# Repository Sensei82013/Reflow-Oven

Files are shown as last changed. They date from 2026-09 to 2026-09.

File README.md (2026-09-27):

# Reflow Oven Controller

A toaster oven converted into a PCB reflow oven, driven by a custom
STM32F103 board with a K-type thermocouple, a solid state relay and a 7"
Nextion touch panel.

The firmware runs a PI loop on the MCU. A host can steer it either from a
small web app over SWD (working today) or from the Nextion panel
(in progress).

---

## System

```mermaid
flowchart LR
    MAINS["120 V AC mains"] --> PSU["PSU<br/>120 VAC to 24 VDC"]
    PSU -->|24 V| SSR["SSR-25DD<br/>solid state relay<br/>3-32 V in, 25 A"]
    SSR -->|switched 24 V| HEAT["Heating element<br/>3.6 ohm, 160 W"]
    HEAT -.->|heat| TC["K-type thermocouple"]
    TC --> MAX["MAX6675<br/>cold-junction comp<br/>+ 12-bit ADC"]
    MAX -->|SPI| MCU["STM32F103C8T6<br/>custom PCB"]
    MCU -->|PA8 PWM<br/>TIM1_CH1| SSR
    MCU <-->|USART1<br/>PA9/PA10| NEX["Nextion NX8048P070-011C<br/>7in 800x480 capacitive"]
    MCU <-->|SWD| HOST["Host PC<br/>OpenOCD + web app"]
    PSU5["5 V supply, 1 A"] --> NEX
```

### Bill of the major pieces

| Part | Detail | Notes |
|---|---|---|
| **MCU** | STM32F103C8T6 | Custom PCB, OSHPark. 64 MHz from **HSI** - the 8 MHz crystal Y1 is not populated |
| **Temperature** | K-type thermocouple to MAX6675 | SPI, 0.25 °C resolution, 220 ms conversion. Terminal block J5 |
| **Heater switch** | SSR-25DD | DC-DC, 3-32 V control, 5-200 V DC out, 25 A. Driven from PA8 |
| **Heating element** | 3.6 Ω at 24 V | 6.7 A, **160 W**. Hugely oversized for bench setpoints - see `skill.md` |
| **Power** | 120 VAC to 24 VDC | Feeds the element through the SSR |
| **Display** | Nextion NX8048P070-011C | 7", 800x480, capacitive, *Intelligent* series. **Needs its own 5 V at 1 A** - no USB power |
| **Debug** | ST-Link V2 on J2 | 3V3 / SWDIO / SWCLK / GND only. **No NRST** |

### Pin map

| Signal | MCU pin | Net / test point |
|---|---|---|
| MAX6675 `~CS` | PA4 | `Thermo_CS`, TP2, indicator D4 |
| MAX6675 `SCK` | PA5 | `Thermo_SCK`, TP3 |
| MAX6675 `SO` | PA6 | `Thermo_SO`, TP4 |
| SSR control | PA8 | `Relay`, J6, TIM1_CH1, indicator D3 |
| USART1 TX -> Nextion RX | PA9 | TP6 |
| USART1 RX <- Nextion TX | PA10 | TP5 (5 V tolerant) |
| SWD | PA13 / PA14 | J2 |

Two board quirks worth knowing before wiring anything:

- **J4 (the 5 V serial header) does not work.** Its BSS138 level shifters are
  rotated one pin position, so a signal arriving there reaches only a MOSFET
  gate - there is no DC path to the MCU. Go directly to **PA9 / PA10**
  (TP6 / TP5). No level shifting is needed in either direction.
- **SW1 selects BOOT0.** In the +3.3 V position the part boots from SRAM and
  never runs your firmware. It belongs in the **GND** position.

---

## Repository layout

```
Hardware/
  KiCad/            schematic, PCB, gerbers, BOM, 3D step
Software/
  webapp/           browser UI + Python bridge (bridge.py, index.html)
  run_webapp.ps1    build, flash, serve the web app
  run_profile.ps1   open-loop step tests, PI profiles, hardware probes
  run_monitor.ps1   plain thermocouple monitor
  Display/          Nextion HMI designs
  Embedded/
    Thermo_Monitor/ the live firmware (all current work)
    Reflow_Oven_STM32_SOURCE_V1_1/  original 2021 firmware, Nextion HMI
    Reflow_Oven_STM32_Source/       earlier revision
skill.md            project goal, architecture and the pitfalls found so far
```

---

## Quick start

Everything is driven from `Software/`, with the ST-Link connected. The
STM32CubeIDE toolchain is used in place, so nothing extra needs installing;
`make` comes from Git Bash.

```powershell
# live temperature only
.\run_monitor.ps1 -Seconds 30

# browser UI: setpoint + Kp/Ki in, temperature and duty out
.\run_webapp.ps1 -Kp 0.2 -Ki 0.002 -MaxDuty 1.5
# then open http://127.0.0.1:8770/

# open-loop step test, for characterising the plant
.\run_profile.ps1 -Mode step -PwmHz 1 -StepDuty 10 -BaseSeconds 180 -Seconds 500 -Csv step.csv
```

The firmware builds in several modes, selected at compile time:

| `MODE=` | What it does |
|---|---|
| *(none)* | thermocouple monitor, no heating |
| `pi` | fixed 30/40/50 °C profile with dwells |
| `step` | open-loop step at a fixed duty, for plant characterisation |
| `hold` | park the output at a duty so the driver can be probed |
| `server` | PI loop steered from the host over SWD - used by the web app |
| `nextion` | **PI loop driven from the Nextion panel** - Start/Stop arm it, Apply sets setpoint and gains, telemetry goes back to the screen |
| `hmi` | Nextion first-contact probe - baud sweep, pin checks, frame dump |
| `tx` / `rx` | continuous transmit / raw receive capture, for tracing wiring |

---

## Status

**Working:** thermocouple readings, SSR drive, PWM on TIM1_CH1, PI loop on
the MCU, web app with live charts and a dead-man switch, all the safety
cutoffs.

**Working on the panel:** wire it **straight to PA9 / PA10** - not J4, whose
level shifters are miswired. `MODE=nextion` is a full controller driven from
the screen: Start and Stop arm and disarm the loop, Apply sets the setpoint
and gains, and the firmware pushes temperature, setpoint, duty, error, state,
the status LED, the P/I split and the trend waveform back to the panel. The
object map is `Software/Display/README.txt`.

**Remaining on the panel:** a run on real hardware to confirm the arming path
end to end. Note the trend waveform's `add` command takes a single byte, so
the trace clips above about 91 °C - fine for bench work, not for a reflow
profile.

**Not started:** reflow profiles proper (soak / ramp / peak / cool),
enclosure, mains-side safety.

See `skill.md` for the detail, and especially for the things that cost real
time to discover.

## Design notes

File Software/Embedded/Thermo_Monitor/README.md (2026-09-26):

# MAX6675 thermocouple live monitor

A small standalone firmware for the Reflow Oven board (STM32F103C8T6) that does
nothing but read the MAX6675 and report the temperature. It never drives the
relay.

## Pin map (from `Reflow Project Kicad.xml`)

| Signal | MCU pin | Net / test point |
|---|---|---|
| MAX6675 `~CS` | PA4 | `Thermo_CS`, TP2 |
| MAX6675 `SCK` | PA5 | `Thermo_SCK`, TP3 |
| MAX6675 `SO`  | PA6 | `Thermo_SO`, TP4 |
| USART1 TX | PA9 | TP6 |
| USART1 RX | PA10 | TP5 |
| Relay | PA8 | J6 (held low here), indicator D3 |

Two indicator LEDs are useful while debugging: **D4 (red) sits on `Thermo_CS`
through R5**, so it is lit whenever CS is high — i.e. whenever this firmware is
actually running and holding the MAX6675 deselected. D4 dark on USB power means
the chip is not executing the flash image at all. **D3 (red) is on the relay
line.** Note D3/D4/R5/R10 postdate `Reflow Project Kicad.xml`; they exist only
in the current `.kicad_sch`.

## Output

The same line goes out three ways, so it can be watched with or without extra
hardware:

1. **USART1, 115200 8N1** on PA9/TP6.
2. **ARM semihosting** over SWD, so an attached ST-Link shows it with no
   USB-serial adapter. Guarded on `C_DEBUGEN`, so the board still runs
   standalone with no debugger.
3. **A telemetry struct at `0x20000000`** that a debugger can poll while the
   core keeps running: `magic("TMP1"), seq, raw, milli_c, fault, uptime_ms,
   sysclk_hz, on_hse`. `seq` is written last, so a changed `seq` means the
   rest is consistent.

Format is `seq,raw,tempC,status`, twice a second.

## Build and run

From Git Bash:

```bash
make
./run_monitor.sh 30                # flash, start, stream 30s of output
./run_monitor.sh 30 --run-only     # skip flashing
```

From Windows PowerShell, which cannot execute `.sh` files, use the equivalent
`.ps1` (note the leading `.\` — PowerShell does not run commands from the
current directory without it):

```powershell
.\run_monitor.ps1 -Seconds 30
.\run_monitor.ps1 -RunOnly
```

Building still needs `make`, so either use Git Bash or build in STM32CubeIDE.
Both runners use the STM32CubeIDE 1.15.0 bundled toolchain, CubeProgrammer and
OpenOCD; no separate installs are needed.

**Only the ST-Link needs to be plugged in.** It supplies 3.3 V to the board
through J2 pin 1 (CubeProgrammer and OpenOCD both report the target voltage,
~3.22 V here) and carries the semihosting output. USB is optional, and powering
from both at once is fine. USB alone gives you a running board but no console —
watch D4, or hang a USB-serial adapter on PA9/TP6 at 115200 8N1.

## Heater control

`control.c` drives the element through the IRF520N on PA8 (the "Relay" net,
J6), which is TIM1_CH1, so duty cycle is real hardware PWM at 200 Hz. D3 sits
on the same net and dims with duty.

```powershell
.\run_profile.ps1 -Mode pi                  # 30/40/50 C profile, PI control
.\run_profile.ps1 -Mode pi -Kp 8 -Ki 0.4    # retune without editing source
.\run_profile.ps1 -Mode step -StepDuty 100  # open-loop step, for tuning
.\run_profile.ps1 -Mode hold -StepDuty 100  # park the output to probe it
.\run_profile.ps1 -Mode pi -Csv out.csv     # also save the rows
```

One script because PowerShell 5.1 has no `&&`; it shells the `make` out to Git
Bash, flashes, runs, and captures. Gains are `-D` macros, so retuning is a
command-line argument rather than a source edit.

### Tuning it for this element

A 41 C setpoint with Kp 12 / Ki 0.6 peaked at **151 C**. Fitting that run
gives the plant, and the numbers explain everything:

| | |
|---|---|
| time constant | ~162 s |
| steady-state gain | **~3860 C per 100% duty** |
| energy delivered | 4.75 full-power-seconds |
| resulting rise | 113 C, i.e. ~24 C per full-power-second |

Duty actually needed to *hold* a setpoint (ambient ~28 C):

| setpoint | duty |
|---|---|
| 41 C | **0.34%** |
| 60 C | 0.83% |
| 100 C | 1.9% |
| 250 C | 5.8% |

The element keeps dumping heat for ~27 s after duty reaches zero, so overshoot
is set by the duty you are *at* when you arrive - not by how fast you cut:

| arriving at | overshoot |
|---|---|
| 0.5% | ~3 C |
| 1.5% | ~10 C |
| 5% | ~32 C |
| 10% | ~64 C |

That is the whole story. Kp 12 commands 100% duty at 8 C of error on a plant
that needs a third of one percent, and by the time the probe reacts the energy
is already committed.

**Suggested starting point:**

```powershell
.
un_webapp.ps1 -Kp 0.2 -Ki 0.002 -MaxDuty 1.5
```

Use `-MaxDuty 0.5` if you want overshoot in the low single digits and are
happy with a slower approach. Raise the ceiling as the setpoint rises - 250 C
needs about 6%. `-MaxDuty` and `-OverTemp` are compiled in; the page cannot
raise them.

Gains are carried as micro-units (x1e6) rather than milli, because Ki of 0.002
is only two counts at a thousandth - not enough resolution to tune with. The
page's step sizes match: 0.01 for Kp, 0.001 for Ki.

**The real fix is less power.** This element is roughly a hundred times
oversized for bench setpoints; the entire useful control range is 0-2% duty,
which is also an awkward pulse width for an SSR at 1 Hz. Running the element
from a lower supply - 12 V quarters the power, 6 V cuts it sixteen-fold -
moves the working range into a comfortable 5-25% band and makes the loop far
better behaved. A real oven with a chamber full of thermal mass will behave
differently again, so treat all of this as calibration of the bench rig.

### Safety

In the firmware: any sensor fault forces duty to 0 (a controller that cannot
see temperature must not drive a heater); above 120 C the output latches off
until reset; every stage times out rather than sitting at full power forever;
the profile switches off and reports DONE.

In the host script: PA8 is forced low through the debugger *before and after*
every run, by enabling the GPIOA clock, clearing the output bit and switching
the pin to a push-pull output while the core is halted. That way neither a
crash nor a halted core can leave the element energised. Reset (SW2) also
drops the gate.

### Status: no heat reaches the thermocouple

The driver stage is fine. Two things were measured that rule it out: PA8's own
pin readback matches the commanded duty exactly, and there is **24 V across
the element at 100% duty**. A MOSFET failing to enhance would drop that supply
across itself and leave the element near 0 V, so the IRF520N is conducting -
an earlier note here blamed its gate threshold and was wrong.

The clean measurement is a cold start: three minutes with the heater off, then
six minutes at 100% duty.

| Segment | Mean |
|---|---|
| heater off, settled (120-180 s) | 27.71 C |
| 100% duty, after 5-6 min (480-540 s) | 27.42 C |
| **steady-state rise** | **-0.29 C** |

Zero, within the MAX6675's 0.25 C quantisation. Six minutes at full power
moves the sensor by nothing at all.

**Two earlier readings of this were wrong, both for the same reason.** The
first step test used a 30-second window and showed nothing, which was read as
"no heating". A later fit gave +15.3 m C/s and was read as "heating, but
slowly". That slope was residual heat from the *previous* run still working
through the rig - this bench holds heat between tests, and the 6-minute run
was climbing 0.4 C/s during its own heater-*off* baseline. Only a cold start
with a long settled baseline measures the heater rather than the last test.
Use `-BaseSeconds 180`.

So: the element dissipates power, and essentially none of it arrives at the
thermocouple. In likely order:

- **Thermal coupling.** If the element is warm to the touch while the probe
  reads ambient, the probe is not seeing it. Still air is an excellent
  insulator; a millimetre of it is enough to hide a low-power element. The tip
  needs physical contact - clamped, taped with foil or kapton, thermal paste.
- **Delivered power.** Measure the element's resistance; 24 V across R gives
  R/576 watts. That the IRF520N passes the current with only 3.3 V on its gate
  suggests the current, and therefore the power, is small.
- **Losses.** An element in open air with no enclosure sheds most of what it
  makes. The real oven will behave completely differently.

No gain value fixes a plant whose output never reaches the sensor. The stage
timeout exists so the firmware reports that rather than sitting at 100%
forever.

### Driving it with an SSR instead

An opto-isolated DC SSR (e.g. SSR-25DD, 3-32 V in, 5-200 V DC out, 25 A) is a
fine replacement for the IRF520N module here - 6.7 A against a 25 A rating is
comfortable, and a resistive element needs no flyback path. Three things to
get right:

1. **Drop the PWM frequency.** An SSR's opto output takes on the order of a
   millisecond to switch. At the 200 Hz default that is a large fraction of
   every 5 ms period spent in transition: it never switches cleanly and the
   SSR heats. Use time-proportioned control instead - `-PwmHz 1`. A plant with
   a minutes-long time constant does not notice, and duty resolution stays at
   0.05% because the period is always 2000 counts.
2. **3.3 V input is the bottom of the range.** PA8 supplies 3.3 V; "3-32 V"
   includes it with no margin at all. If it switches unreliably, buffer it -
   VBUS (5 V) is on J4 pin 3 - or keep the MOSFET module as the buffer stage.
   Input current is typically 7-15 mA, within PA8's budget. D3 + R10 stay in
   parallel on the Relay net and are harmless.
3. **Heatsink it, and watch polarity.** At 6.7 A even a 0.3 V drop is ~2 W.
   DC SSRs are polarity-sensitive on *both* input and output.

Note this part is DC-only. A mains-powered oven needs the AC version.

The cheaper fix is a logic-level MOSFET (IRLZ44N, IRLB8721) in place of the
IRF520N, which keeps 200 Hz switching. The SSR buys isolation and headroom.

### Commissioning a working switch

3.6 ohm at 24 V is 160 W - far more than these setpoints need, and enough to
overshoot hard before a 250 ms loop can react. Start capped and gentle:

```powershell
.\run_profile.ps1 -Mode step -PwmHz 1 -StepDuty 10 -BaseSeconds 180 -HeatSeconds 240 -Seconds 500 -Csv step10.csv
.\run_profile.ps1 -Mode pi -PwmHz 1 -MaxDuty 20 -DwellSeconds 60 -Csv pi.csv
```

The step test at low duty gives a rise curve to pick gains from without
cooking anything. Raise `-MaxDuty` only once the response is known.

## Web app

`run_webapp.ps1` builds the server firmware, flashes it, starts OpenOCD and
serves a small control page:

```powershell
.\run_webapp.ps1                      # 1 Hz PWM, initial duty cap 20%
.\run_webapp.ps1 -MaxDuty 60 -Setpoint 45
.\run_webapp.ps1 -NoBuild             # skip the build entirely
.\run_webapp.ps1 -ForceFlash          # reflash even if unchanged
```

Then open <http://127.0.0.1:8770/>. Ctrl-C stops everything.

**It only flashes when the chip does not already hold this image.** The binary
is read back and compared first, so restarting the app does not erase/program
on every launch or reset the board out from under whatever was running.
`-ForceFlash` overrides, and the build is incremental so an unchanged tree is
a no-op too.

**The duty cap is a runtime value.** `-MaxDuty` seeds it; the page changes it
live, and the page's fields adopt whatever the bridge started with so they
never misreport the live cap. `MAX_DUTY` in the Makefile is a different thing:
a build-time hard ceiling for a firmware that physically cannot exceed some
duty. It defaults to 100 so the UI control is honest - lower it only when you
want that guard baked in.

It shows live temperature, setpoint, duty and error, charts temperature
against setpoint and duty on a second axis-free chart below, and lets you set
a setpoint, cap the duty, start and stop.

### How it reaches the board

The board has no network of its own - no Ethernet, and USB device mode is out
while Y1 is unpopulated - so the only live path is SWD:

```
browser <-- HTTP --> webapp/bridge.py <-- TCL --> OpenOCD <-- SWD --> board
```

The firmware (`MODE=server`) runs the PI loop itself at 4 Hz. OpenOCD reads
and writes target memory through the DAP **while the core keeps running**, so
the control loop is never halted by the UI. The bridge finds both blocks by
running `nm` over the ELF, so the layout is never duplicated between firmware
and host.

**The page sends three numbers and nothing else: setpoint, Kp, Ki.** Duty is
computed on the MCU and only reported back, so a stalled browser or a slow
HTTP round trip can never stretch or skip a control step.

Both blocks use the same discipline: the writer fills the fields and bumps
`seq` last; the reader only acts on a block whose seq changed. A half-written
update cannot be acted on.

### The loop

Textbook PI with two details worth knowing:

- **The integral stores accumulated error (C.s), not an output contribution.**
  The I term is always `Ki * integ_err`, so retuning Ki does not leave history
  that means something different than it did a moment ago.
- **Ki changes are bumpless.** When Ki moves, `integ_err` is rescaled so the I
  term comes out where it already was. Without that, nudging Ki while hot
  steps the output - and on this element that is a real temperature
  excursion, not a cosmetic glitch.
- Anti-windup is conditional integration: accumulate only when the result
  would not be against a stop.

P and I are published separately from the duty they sum to, and the page plots
all three. Seeing which term is doing the work is the whole game when tuning
by hand.

### Safety

- **Dead-man switch.** The firmware only heats while it receives a heartbeat,
  and the bridge only relays that heartbeat while a client has called the API
  within 2.5 s. Close the tab and the output stops within a few seconds.
  Verified: enable -> `running`, client silent 9 s -> `host timeout` at 0%.
- **Explicit re-arm.** After a dead-man trip the firmware clears its own
  enable flag, so heating never resumes just because a browser reconnected -
  it takes a new Start. `push_command` refreshes the heartbeat *before* the
  seq write, otherwise that Start would be latched and cleared in the same
  cycle and nothing would ever re-arm it.
- Sensor fault forces duty to 0; over 120 C latches off until reset; duty is
  capped by `-MaxDuty` on top of whatever the loop asks for.
- Setpoint and duty are range-checked in the bridge as well as clamped in
  firmware. The browser is the least trustworthy part of the chain.

The bridge binds to 127.0.0.1 only. Don't expose it - there is no auth, and
the far end is a 160 W heater.

## Board quirks this firmware works around

These are properties of the board, not of the code, and they cost real time to
rediscover:

- **No NRST on the debug header.** J2 carries only 3V3/SWDIO/SWCLK/GND. `NRST`
  reaches only pushbutton SW2. A debugger therefore cannot pull reset, and
  `mode=UR` / plain `reset` do not do what they normally would.
- **SW1 sets the boot mode, and the +3.3V position bricks the board.** SW1 is
  an SPDT between +3.3V (pin 1) and GND (pin 3), feeding BOOT0 through R1;
  BOOT1/PB2 is unconnected and floats high, so BOOT0 high selects boot-from-
  SRAM and the chip never executes flash — after a reset the PC lands in SRAM.
  **SW1 belongs in the GND position**, where it is now; the board then boots
  the firmware on its own, on USB power, with no debugger attached.
- **Stale breakpoints.** CubeProgrammer's flash loader leaves a hardware
  breakpoint armed in SRAM, which traps the core as soon as it runs. The run
  script issues `rbp all` / `rwp all` before resetting.
- **Interrupt masks survive a manual start.** Only relevant if you start the
  core by hand rather than resetting it: a previous HardFault leaves `PRIMASK`
  set, SysTick then never ticks, `HAL_GetTick()` freezes, and every HAL
  timeout loop — including the HSE-ready wait — spins forever.
- **J4, the 5 V serial header, does not work - its level shifters are
  miswired.** (An earlier note here said U2's `OE` was tied low; that was read
  off the stale `.xml` netlist. **U2 does not exist on the current board at
  all** - it was replaced by two BSS138s, Q1 and Q2.)

  A BSS138 bidirectional shifter wants gate on the +3.3V *rail*, source on the
  3.3V signal, drain on the 5V signal. As built, the three connections are
  rotated one position (symbol pins are 1=G, 2=S, 3=D):

  | | gate (pad 1) | source (pad 2) | drain (pad 3) |
  |---|---|---|---|
  | Q2 (TX) | `3.3_USART1_TX_v1` (PA9) | `/USART1_TX_5V` (J4.2) | dead end -> R8 -> VBUS |
  | Q1 (RX) | `3.3_USART1_RX_v1` (PA10) | `/USART1_RX_5V` (J4.1) | dead end -> R7 -> VBUS |

  So on TX the part runs as a source follower: a high comes out at roughly
  3.3V - Vgs(th), about 2 V, and a low leaves the pin floating because nothing
  pulls J4.2 down. On RX the gate is the MCU's *input*: when the far end pulls
  the source low the FET conducts, but that only drags the dangling drain
  down - PA10 stays at 3.3 V through R6 and never sees a low. Both directions
  are broken.

  Usable UART is therefore at **TP6 (PA9, TX) and TP5 (PA10, RX)**, both plain
  3.3 V with 10k pull-ups (R9, R6). To make J4 live at 3.3 V instead, bridge
  pads 1-2 of Q1 and Q2 (1.90 mm apart, one 0603 zero-ohm each); R7/R8 then
  just hold the floating drains at 5 V, which is harmless.

## Clocking: no crystal fitted

**Y1 is not populated**, so there is no HSE. The firmware runs from the
internal oscillator instead — HSI/2 through PLL x16 = 64 MHz — and says so at
startup:

```
SYSCLK 64000000 Hz (internal HSI, Y1 not populated), sampling every 500 ms
```

HSI is inside the MCU, so nothing needs routing. The only cost is accuracy:
roughly +/-1% at room temperature and a few percent across the full range,
against tens of ppm for a crystal. That does not matter here — the MAX6675
does its own conversion and SCK has no minimum rate — and it is comfortably
inside what a 115200 UART tolerates.

What it does rule out is **USB device mode**, which needs 48 MHz derived from
an HSE PLL and cannot be synthesised from HSI on an F103. So J1 is power-only
unless Y1 gets populated, even though D+/D- and the R2 pull-up are routed.

If the crystal is ever fitted, build with `-DUSE_HSE=1` (or flip `USE_HSE` in
`Core/Src/main.c`) to get 72 MHz from it; the code still falls back to HSI if
it fails to start, rather than hanging.

## Schematic and PCB audit of U4

Checked against the MAX6675 datasheet pinout (1 GND, 2 T-, 3 T+, 4 VCC,
5 SCK, 6 ~CS, 7 SO, 8 N.C.). **The design is correct** - the fault is not in
the routing:

| Pin | Datasheet | Board | Copper |
|---|---|---|---|
| 1 | GND | GND | GND pour, F.Cu + B.Cu |
| 2 | T- | GND | GND pour, F.Cu + B.Cu |
| 3 | T+ | `Net-(U4-T+)` -> J5.1 | track |
| 4 | VCC | +3.3V | track |
| 5 | SCK | `Thermo_SCK` -> PA5, TP3 | track |
| 6 | ~CS | `Thermo_CS` -> PA4, TP2 | track |
| 7 | SO | `Thermo_SO` -> PA6, TP4 | track |
| 8 | N.C. | unconnected | none (correct) |

- **Continuity verified in copper**, not just in the netlist: for each of
  `Thermo_SCK`, `Thermo_CS` and `Thermo_SO`, the MCU pad, the test point and
  the U4 pad all land on a single connected island. SCK specifically runs
  U1.15 -> TP3 -> U4.5 unbroken.
- **T- is grounded**, as the datasheet's typical application circuit requires.
  It connects through the pour rather than a track, which is why a
  segments-only check wrongly reports it as unrouted - the board has 8 zones,
  including GND pours on both layers.
- **Decoupling is present**: C18 (100n) sits 5.3 mm from U4 across +3.3V/GND,
  satisfying the datasheet's bypass recommendation.
- Not fitted, and optional per the datasheet: a filter capacitor across
  T+/T-. Worth adding only if readings turn out noisy once the part responds.

One note for whoever reflows U4: pins 1 and 2 tie straight into a pour on both
layers with `connect_pads yes` and no thermal relief, so they sink a lot of
heat. That makes a hand-soldering iron much less effective on that side.

### Pin-to-pin short test

`probe_shorts()` rules out the other defect that fits the symptom: a bridge
between the adjacent pins 5/6/7. If CS and SO were bridged, SO would simply
mirror CS - high while deselected, low throughout a transfer - which looks
exactly like all-zeros data. The test pulls SO *down* while CS is high; the
MAX6675 releases SO then, so a 1 would mean CS is driving it through a bridge.
Measured result:

```
short: CS->SO=0  SCK->SO=0/1  SCK->CS=0/0
short: no pin-to-pin short found
```

No bridge. (`SCK->CS` reading 0/0 rather than 0/1 is just D4+R5 loading the CS
net - a 1k5 LED leg beats the MCU's ~40k internal pull-up. Harmless, since the
firmware drives CS push-pull.)

## Resolved: U4 VCC pin was lifted

**Fixed 2026-09-19.** The MAX6675's 3V3 pin (4) was lifted off its pad. The
part still answered chip select the whole time — SO released when CS went
high and was driven low when CS went low — because the die was scavenging
power through its I/O clamp diodes from CS. That is enough to work the output
stage but not the shift register, so every word came back `0x0000`.

Worth remembering, because it is a genuinely misleading failure: **a part that
responds to CS is not necessarily powered.** The symptom is indistinguishable
from a missing clock, and the design audit above was needed to get there —
schematic and PCB were both correct.

After reseating the pin:

```
SYSCLK 64000000 Hz (internal HSI, Y1 not populated), sampling every 500 ms
bus: SO(CS=1)=1 SO(CS=0)=0  SCK readback hi=1 lo=0
bus: SO per clock = 0000001101111001
1,0x0381,28.00,OK
2,0x0371,27.50,OK
3,0x0389,28.25,OK
```

Readings sit within +/-0.25 C, which is one MAX6675 LSB — quantisation, not
noise. `RUN_BUS_PROBE` is now 0; set it back to 1 if the sensor ever goes
quiet again.

### If it goes quiet again

The startup diagnostics distinguish the likely causes without a meter:

| `bus:` line | Meaning |
|---|---|
| `SO(CS=1)=1 SO(CS=0)=0`, all-zero words | Part answers CS but cannot shift — VCC or SCK not reaching the die |
| `SO(CS=1)=1 SO(CS=0)=1` | Nothing driving SO at all — part absent, or CS/SO open |
| `short:` reports a bridge | Solder bridge between the adjacent pins 5/6/7 |
| Words read `0xFFFF` | SO floating; reported as `NO_SENSOR_REPLY` |
| D2 set in the word | Thermocouple unplugged; reported as `OPEN_THERMOCOUPLE` |

`0x0000` and `0xFFFF` are both rejected rather than reported as 0 C.

With a meter, probe the U4 pins themselves rather than the test points — the
test points only prove the trace, not the joint. Pin 4 to pin 1 should read
3.3 V, and pin 6 should read 3.3 V while idle. For the clock:

```bash
make SCK_TEST=1 && ./run_monitor.sh 5
```

holds CS low and drives SCK as a 1 kHz square wave, which a DC meter reads as
roughly half of 3.3 V, so **TP3 and U4 pin 5 should both sit near 1.6 V**.
TP3 at 1.6 V with pin 5 stuck at 0 V or 3.3 V localises the break to the chip.
Rebuild with plain `make` afterwards.

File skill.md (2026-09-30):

# Reflow Oven - project brief and hard-won pitfalls

Read this before touching the hardware. Nearly every item below cost hours to
find and looks like something else when you hit it.

---

## Goal

Turn a toaster oven into a PCB reflow oven. An STM32F103 reads a K-type
thermocouple through a MAX6675, drives a 160 W element through a solid state
relay, and runs a PI loop to hold temperature. A 7" Nextion panel is the
intended user interface; a browser app over SWD exists as a working stand-in.

The end goal is a proper reflow profile - soak, ramp, peak, cool - commanded
from the panel.

---

## Architecture

The PI loop lives **on the MCU** and owns the duty cycle. Hosts only supply a
setpoint and gains. That boundary is deliberate: a stalled browser or a slow
HTTP round trip can then never stretch or skip a control step.

```
browser  --HTTP-->  webapp/bridge.py  --TCL-->  OpenOCD  --SWD-->  board
```

The board has no network of its own and USB device mode is unavailable (see
the crystal note below), so SWD is the only live path. OpenOCD reads and
writes target memory through the DAP **while the core keeps running**, so the
UI never halts the control loop.

Two RAM blocks carry the traffic, `g_cmd` and `g_srv`, located by running
`nm` over the ELF rather than hard-coding addresses. Both use the same
discipline: the writer fills the fields and bumps `seq` **last**, and the
reader acts only on a block whose seq changed, so a half-written update can
never be acted on.

---

## Pitfalls

### Flashing and boot

- **No NRST on the debug header.** J2 carries only 3V3/SWDIO/SWCLK/GND, so a
  debugger cannot pull reset and `mode=UR` does not do what it normally does.
  Reset goes through the Cortex-M `SYSRESETREQ` bit instead - see
  `openocd.cfg`.
- **SW1 selects BOOT0, and the wrong position looks like a dead board.** With
  BOOT1/PB2 floating high, BOOT0 high means boot-from-SRAM and the part never
  executes flash; after reset the PC lands around `0x2000xxxx`. **SW1 belongs
  in the GND position.** Visible tell: D4 (on `Thermo_CS`) is lit whenever
  firmware is actually running.
- **CubeProgrammer leaves a hardware breakpoint armed** in SRAM, which traps
  the core the moment it runs. Issue `rbp all` / `rwp all` before resetting.
- **Interrupt masks survive a manual start.** If you ever start the core by
  hand rather than resetting it, a previous HardFault leaves `PRIMASK` set;
  SysTick then never ticks, `HAL_GetTick()` freezes, and every HAL timeout
  loop spins forever - including the HSE-ready wait, which looks like a
  hung boot.

### Clock

- **Y1 is not populated.** There is no HSE. Everything runs from HSI through
  the PLL at 64 MHz. Do not treat "HSE not ready" as a fault.
- Consequence: **USB device mode can never work** as populated, because the
  F103 needs 48 MHz from an HSE PLL. J1 is power-only despite D+/D- and the
  R2 pull-up being routed.

### Build system

- **Changing a `-D` flag used to silently keep stale objects.** Object files
  depend on sources, not on the command line, so `make MODE=server
  MAX_DUTY=10` after a `MAX_DUTY=30` build did nothing and shipped the old
  binary. Combined with the runner's flash-skip, a requested duty ceiling
  silently never existed and the heater overshot by 30 °C. Fixed with a flags
  stamp (`build/flags.stamp`) that every object depends on. If a `-D`
  controlled limit seems not to take effect, hash the binary before and after
  rather than trusting "Nothing to be done".

### Thermocouple

- **A part that answers chip select is not necessarily powered.** The MAX6675
  once returned `0x0000` forever while still releasing SO when CS went high
  and driving it low when CS went low. It was scavenging power through its
  I/O clamp diodes from CS - its **3V3 pin was lifted**. The symptom is
  indistinguishable from a missing clock. Check power *at the pin* before
  suspecting the clock or the code.
- `0x0000` and `0xFFFF` are **not** valid frames and are reported as
  `NO_SENSOR_REPLY`, never as 0 °C. An unplugged thermocouple sets D2 and
  reads `OPEN_THERMOCOUPLE` instead.
- The design was audited against the datasheet and is correct: pinout matches,
  SCK/CS/SO are continuous in copper, C18 decouples VCC, T- is grounded.
  **Gotcha when auditing this PCB:** it has 8 copper zones, and the syntax is
  `(zone (net 2) (net_name "GND")`. A segments-and-vias-only continuity check
  wrongly reports every pour-connected pad as unrouted - U4 pin 2 especially.

### Heater drive

- **The original IRF520N could not switch this load from 3.3 V logic.**
  R_DS(on) is specified at V_GS = 10 V and V_GS(th) is 2-4 V, so a 3.3 V gate
  leaves it near threshold. Replaced with an SSR-25DD, which works.
- **The module is a low-side switch**, so measuring V+ to GND reads 24 V
  whether or not the FET conducts. That measurement fooled us into clearing
  the driver when it was in fact the problem. Measure **drain to source**, or
  across the element.
- **SSRs cannot follow fast PWM.** An opto-isolated DC SSR takes roughly a
  millisecond to switch, so at 200 Hz it never switches cleanly. Duty
  resolution stays at 0.05 % because the period is always 2000 counts.
  `PWM_HZ` now **defaults to 1**; the old 200 Hz default belonged to the
  IRF520N and, left in place, is a silent no-op. At 200 Hz a 1 % duty is a
  48 us pulse, about twenty times shorter than the relay can respond to, so
  the loop reports a sensible duty and the element gets nothing at all.
- **Halting the core does NOT stop the heater** - TIM1 is hardware and keeps
  driving PA8. A capture that ended early once left the element at 3.25 % duty
  indefinitely with no control loop behind it, because the host script's park
  step never got to run. `heater_init()` now sets `__HAL_DBGMCU_FREEZE_TIM1()`,
  so any debugger halt stops the timer too. Treat "the debugger stopped" as a
  state that must be safe by construction, not one the tooling cleans up.
- **`heater_off()` is destructive, so arming again must be explicit.** It stops
  the timer and reconfigures PA8 as a plain GPIO output low, deliberately, so
  the pin is held down by the GPIO block even if the timer misbehaves. But
  `heater_set()` only writes CCR1, which does nothing in that state - so any
  mode that called `heater_off()` during setup could never produce output
  again, at any duty. `heater_set()` now re-arms when it is asked for a
  non-zero duty and finds `TIM1_CEN` clear. Verify with the registers, not the
  log: the loop happily prints "HEATING duty 1.0 %" with the output dead.
  `GPIOA_CRH` nibble 0 must read `A`, not `2`, and `CR1` bit 0 must be set.
- **Very low duties are near the relay's limit.** Holding 41 C needs 0.34 %,
  which at 1 Hz is a 6.8 ms pulse against a switching time of about 1 ms. It
  works, but the delivered energy is non-linear down there. If that becomes a
  problem the answer is a longer time-proportioning window, not a gain change -
  or a less absurdly oversized element.

### The plant itself

Measured, not guessed:

| | |
|---|---|
| Time constant | ~162 s |
| Steady-state gain | **~3860 °C per 100 % duty** |
| Energy to temperature | ~24 °C per full-power-second |

Duty needed to **hold** a setpoint (ambient ~28 °C): **0.34 % at 41 °C**,
0.83 % at 60 °C, 1.9 % at 100 °C, 5.8 % at 250 °C.

The element keeps dumping heat for ~27 s after duty reaches zero, so
**overshoot is set by the duty you are at when you arrive**, not by how fast
you cut:

| arriving at | overshoot |
|---|---|
| 0.5 % | ~3 °C |
| 1.5 % | ~10 °C |
| 5 % | ~32 °C |
| 10 % | ~64 °C |

So textbook gains are actively dangerous here. Kp = 12 %/°C commands full
power at 8 °C of error on a plant that needs a third of one percent; a run to
a 41 °C setpoint peaked at **151 °C**. Start around **Kp 0.2, Ki 0.002,
`-MaxDuty 1.5`** and raise the ceiling only as the setpoint rises.

Gains are carried as micro-units (x1e6) rather than milli, because Ki of 0.002
is only two counts at a thousandth - not enough resolution to tune with.

**This is dead-time dominated.** No gain value fixes that; the duty ceiling
does the real work. Note also that the element position and insulation are
expected to change, so do not over-tune the current rig.

### Nextion panel

**Wire the panel straight to PA9 / PA10. That works.**

| Panel | Board |
|---|---|
| TX | **PA10** (TP5) - 5 V tolerant, no level shifter needed |
| RX | **PA9** (TP6) - 3.3 V drive is sufficient |
| GND | board GND |
| 5 V | its own supply - 430 mA typical, 1 A recommended |

**Do not use J4.** Its BSS138 shifters have the pins rotated one position, so
a signal arriving there lands on a MOSFET gate and there is simply no DC path
to the MCU. Everything else - baud, levels, grounds - was a red herring; this
was the whole problem, and it cost a lot of time. TP5/TP6 sit directly on the
MCU nets with nothing in between.

Confirmed working once moved: the panel answers `sendme` with
`66 00 FF FF FF` at 9600, and `dim=` visibly changes the backlight.

The panel is an **NX8048P070-011C**: 7", 800x480, capacitive, *Intelligent*
series, default baud 9600, **no USB power**.

See `Software/Display/README.txt` for the full object map - that file is the
contract, and `MODE=nextion` implements it. Four things about it shape the
firmware:

- **Search the HMI for `prints`, not `print`.** An earlier audit of this panel
  concluded that Start and Stop emitted nothing, because the grep only looked
  for `print`. They use `prints "p0b20"` / `prints "p0b21"` and always worked.
  A wrong "the panel sends nothing" sends you looking at wiring for no reason.
- **Page scope matters, but only for some objects now.** `xPV/xSP/xDuty/xErr`
  and `xSPset/xKp/xKi` are `vscope=global` and can be written from any page.
  `tState`, `tLed`, `tMode`, `tAlarm`, `tPI` and the waveform `s0` are still
  page-local, so writing them while another page is up returns `1A`. The
  firmware tracks the page from the nav codes `p0b10/11/12` and gates only
  those. Monitor is page **0** and the boot page - do not assume page 1.
- **9600 baud is only ~960 byte/s, and that is a real constraint.** Four
  `x.val=` writes per 250 ms cycle is already a quarter of the link. Send the
  numbers every cycle and the text and colours only when they change,
  otherwise the queue backs up and the screen lags behind the plant.
- **Never leave `bkcmd=1` on.** It makes the panel return a bare `0x01` after
  every command, and those acks are single bytes with no terminator. Four
  telemetry writes per 250 ms cycle fill a 64-byte frame buffer in about four
  seconds, after which every arriving byte is discarded and no touch code is
  ever parsed again. The failure is silent and deeply misleading: telemetry is
  TX-only so the screen keeps updating perfectly, and the dead-man stays happy
  because bytes *are* arriving - only the parser is jammed. It presents as
  "the buttons do nothing". Use `bkcmd=0`, and make buffer overflow reset the
  frame rather than drop the bytes that would have ended it.
- **Do not poll the UART from the control loop.** The MAX6675 conversion is
  220 ms of a 250 ms cycle and the telemetry writes are blocking on top of it,
  so a polled receive gets almost no time, drops bytes, and the dead-man trips
  at random - it looks exactly like a flaky panel or a bad wire. `MODE=nextion`
  claims `USART1_IRQn` (unused by this project's MSP) and receives into a ring
  buffer instead. A cycle that overruns also resyncs its deadline rather than
  chasing it, so it never spirals.
- **The waveform `add` command takes a single byte.** `add 1,0,<y>` cannot
  address rows above 255, so with the contract's 2.8 px/°C scale the trace
  clips at about 91 °C. Enough for bench work; a reflow profile will need
  either a coarser scale or `addt` bulk transfer.

### Long unattended runs

A 30-minute hold test cannot have a debugger attached for its duration, and
getting that right took several attempts:

- **Semihosting output is the hazard.** Any attach sets `C_DEBUGEN`; a
  `bkpt #0xAB` reached while no servicer is listening halts the core *for
  good*. So merely peeking at a run kills it - a read-only check stopped a
  hold test dead. Build long runs with **`NX_QUIET=1`**, which makes the mode 8
  loop silent, and the board can then be attached to and read at will. Note
  `main()`'s own banner is still noisy, so the arming session must enable
  semihosting even for a quiet build.
- **Read the trace, not the log.** `g_trace` is a RAM ring - 512 samples of
  temperature and duty at 5 s, i.e. 42 minutes - read over SWD afterwards.
  `g_nx` carries the panel counters the same way.
- **Detach by clearing `C_DEBUGEN`**: `mww 0xE000EDF0 0xA05F0000` as the last
  command. OpenOCD's `shutdown` leaves it set, so the firmware would otherwise
  halt at its next bkpt.
- **Read memory without halting.** `mdw` works on a running target. Issuing
  `resume` to an already-running core errors with `not halted` and **aborts
  the rest of the OpenOCD command sequence**, which is how one peek skipped
  its own `C_DEBUGEN` cleanup and killed the run.
- **Background tasks get truncated** somewhere around 5 minutes, and a
  truncated capture is exactly the case that used to leave the heater on.

### Measuring things - lessons

Two of our own instruments gave confidently wrong answers:

- **HAL calls inside a timing loop measure themselves.** A pin rise-time test
  using `HAL_GPIO_ReadPin` returned a constant 40 cycles regardless of the
  pin, because that *was* the loop overhead. Use raw register access
  (`GPIOA->IDR`, `GPIOA->BSRR`) and measure the floor explicitly.
- **`HAL_UART_Transmit_IT` needs the USART1 NVIC line**, which this firmware's
  MSP never enables. It queues a transfer that can never run, leaves `gState`
  stuck at `BUSY_TX`, and silently turns every later `HAL_UART_Transmit` into
  a no-op. Poll `TXE` and write `DR` directly.

---

## Safety

Present in firmware and worth preserving:

- Any sensor fault forces duty to 0. A controller that cannot see temperature
  must not drive a heater.
- Above `OVERTEMP` (default 120 °C) the output **latches off**. Temperature
  keeps being published while latched - that is exactly when you want to see
  it. In `MODE=nextion`, **STOP clears the latch** once the oven has cooled
  below `OVERTEMP_REARM_C` (15 °C of hysteresis). Until that was added the
  latch was cleared nowhere in the firmware at all, so one trip meant
  power-cycling the board before it would heat again - which presents as "the
  controller is stuck". Requiring a real cool-down keeps STOP a reset button
  rather than a bypass.
- Every profile stage times out rather than sitting at full power forever.
- **Dead-man switch:** the firmware only heats while it receives a heartbeat,
  and the bridge only relays that heartbeat while a client has called the API
  within 2.5 s. Close the browser tab and the output stops within seconds.
  After a trip the firmware clears its own enable flag, so heating never
  resumes just because a browser reconnected - and `push_command` refreshes
  the heartbeat *before* the seq write, otherwise an explicit Start would be
  latched and cleared in the same cycle and nothing would ever re-arm.
- The host scripts force PA8 low through the debugger before and after every
  run, so neither a crash nor a halted core can leave the element energised.
- `MAX_DUTY` and `OVERTEMP` are compiled in; the UI cannot raise them.

The bridge binds to 127.0.0.1 only. Do not expose it - there is no auth and
the far end is a 160 W heater on mains-derived power.

---

## Suggested next steps

1. Run `MODE=nextion` on the bench and confirm the arming path end to end:
   Start turns `tState` green and raises duty, Stop drops it, Apply moves the
   setpoint. The semihosting log prints every touch code it decodes, so a
   button that does nothing is easy to tell from a button that was never sent.
2. Fix the trend waveform's 91 °C ceiling - see the `add` note above.
3. Re-characterise the plant once the element position and insulation are
   final, then set gains and the duty ceiling from that.
5. Implement proper reflow profiles on top of the working setpoint loop.

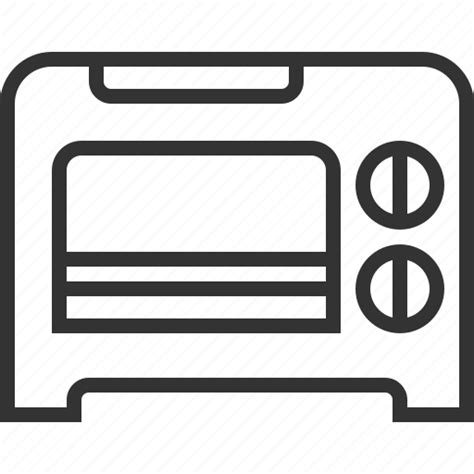
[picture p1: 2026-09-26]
Hardware/KiCad/th.jpg

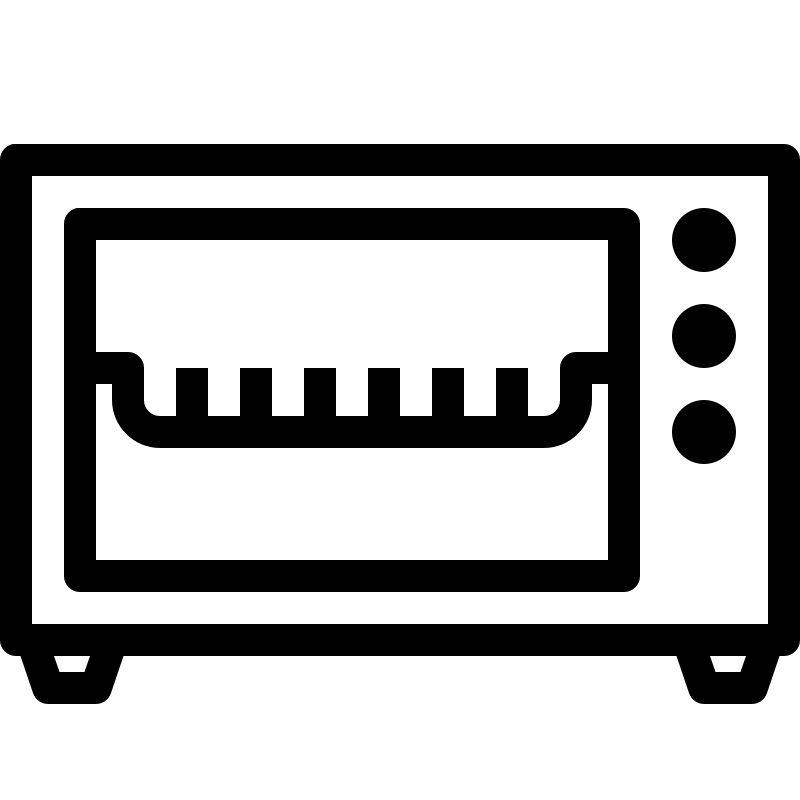
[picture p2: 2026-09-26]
Hardware/KiCad/toaster-oven-svgrepo-com.png

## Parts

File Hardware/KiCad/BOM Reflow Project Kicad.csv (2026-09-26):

Id | Designator | Footprint | Quantity | Designation | Supplier and ref
1 | R4,R2 | R_0603_1608Metric | 2 | 1k5
2 | R3,R1 | R_0603_1608Metric | 2 | 10k
3 | U4 | SOIC127P600X175-8N | 1 | MAX6675ISA_
4 | J3,J5 | CUI_TB001-500-02BE | 2 | CUI_TB001-500-02BE
5 | H1,H2,H3,H4 | MountingHole_3.2mm_M3_DIN965_Pad | 4 | GND
6 | SW1 | SW_EG1271A | 1 | SW_Nidec_CAS-120A1
7 | SW2 | SW_PUSH_6mm | 1 | SW_Push
8 | TP4 | TestPoint_THTPad_1.0x1.0mm_Drill0.5mm | 1 | Thermo_SO
9 | TP3 | TestPoint_THTPad_1.0x1.0mm_Drill0.5mm | 1 | Thermo_SCK
10 | TP2 | TestPoint_THTPad_1.0x1.0mm_Drill0.5mm | 1 | Thermo_CS
11 | TP8,TP10,TP11,TP9,TP12,TP1,TP7 | TestPoint_THTPad_1.0x1.0mm_Drill0.5mm | 7 | VBUS
12 | J1 | USB_Micro-B_Molex-105017-0001 | 1 | USB_B_Micro
13 | J4,J2 | PinHeader_1x04_P2.54mm_Vertical | 2 | Conn_01x04_Pin
14 | C18,C10,C9,C5,C4,C3,C2,C1 | C_0402_1005Metric | 8 | 100n
15 | C8,C7 | C_0402_1005Metric | 2 | 15p
16 | C6 | C_0805_2012Metric | 1 | 10u
17 | Y1 | ATS08A-E | 1 | ATS08A-E (8MHz)
18 | U2 | TSSOP-20_4.4x6.5mm_P0.65mm | 1 | TXS0108EPW
19 | TP5 | TestPoint_THTPad_1.0x1.0mm_Drill0.5mm | 1 | USART1_RX_v2
20 | D2 | LED_0603_1608Metric | 1 | GREEN1
21 | TP6 | TestPoint_THTPad_1.0x1.0mm_Drill0.5mm | 1 | USART1_TX_v2
22 | C16,C17 | C_0805_2012Metric_Pad1.18x1.45mm_HandSolder | 2 | 1u
23 | U3 | SOT-223-3_TabPin2 | 1 | AMS1117-3.3
24 | U1 | LQFP-48_7x7mm_P0.5mm | 1 | STM32F103C8T6

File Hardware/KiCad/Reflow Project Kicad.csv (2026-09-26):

Source: | C:\Users\15129\Desktop\Reflow Oven\Reflow Oven Kicad\Reflow Project Kicad.kicad_sch
Date: | 2/3/2025 18:29
Tool: | Eeschema 7.0.10
Generator: | C:\Program Files\KiCad\7.0\bin\scripting\plugins/bom_csv_grouped_by_value_with_fp.py
Component Count: | 50
Ref | Qnty | Value | Cmp name | Footprint | Description | Vendor | DNP
C1, C2, C3, C4, C5, C9, C10, C18 | 8 | 100n | C | Capacitor_SMD:C_0402_1005Metric | Unpolarized capacitor
C6 | 1 | 10u | C | Capacitor_SMD:C_0805_2012Metric | Unpolarized capacitor
C7, C8 | 2 | 15p | C | Capacitor_SMD:C_0402_1005Metric | Unpolarized capacitor
C16, C17 | 2 | 1u | C | Capacitor_SMD:C_0805_2012Metric_Pad1.18x1.45mm_HandSolder | Unpolarized capacitor
D1 | 1 | GREEN | LED | LED_SMD:LED_0603_1608Metric | Light emitting diode
D2 | 1 | RED | LED | LED_SMD:LED_0603_1608Metric | Light emitting diode
H1, H2, H3, H4 | 4 | GND | MountingHole | MountingHole:MountingHole_3.2mm_M3_DIN965_Pad | Mounting Hole without connection
J1 | 1 | USB_B_Micro | USB_B_Micro | Connector_USB:USB_Micro-B_Molex-105017-0001 | USB Micro Type B connector
J2, J4 | 2 | Conn_01x04_Pin | Conn_01x04_Pin | Connector_PinHeader_2.54mm:PinHeader_1x04_P2.54mm_Vertical | Generic connector, single row, 01x04, script generated
J5, J6 | 2 | 1760510000 | 1760510000 | CONN2_1760510000_WED
R1, R3 | 2 | 10k | R | Resistor_SMD:R_0603_1608Metric | Resistor
R2, R4, R5 | 3 | 1k5 | R | Resistor_SMD:R_0603_1608Metric | Resistor
SW1 | 1 | SW_Nidec_CAS-120A1 | SW_Nidec_CAS-120A1 | EG1271A:SW_EG1271A | Switch, single pole double throw
SW2 | 1 | SW_Push | SW_Push | Button_Switch_THT:SW_PUSH_6mm | Push button switch, generic, two pins
TP1, TP7, TP8, TP9, TP10, TP11, TP12 | 7 | VBUS | TestPoint | TestPoint:TestPoint_THTPad_1.0x1.0mm_Drill0.5mm | test point
TP2 | 1 | Thermo_CS | TestPoint | TestPoint:TestPoint_THTPad_1.0x1.0mm_Drill0.5mm | test point
TP3 | 1 | Thermo_SCK | TestPoint | TestPoint:TestPoint_THTPad_1.0x1.0mm_Drill0.5mm | test point
TP4 | 1 | Thermo_SO | TestPoint | TestPoint:TestPoint_THTPad_1.0x1.0mm_Drill0.5mm | test point
TP5 | 1 | USART1_RX_v2 | TestPoint | TestPoint:TestPoint_THTPad_1.0x1.0mm_Drill0.5mm | test point
TP6 | 1 | USART1_TX_v2 | TestPoint | TestPoint:TestPoint_THTPad_1.0x1.0mm_Drill0.5mm | test point
TP13 | 1 | USART1_TX | TestPoint | TestPoint:TestPoint_THTPad_1.0x1.0mm_Drill0.5mm | test point
TP14 | 1 | USART1_RX | TestPoint | TestPoint:TestPoint_THTPad_1.0x1.0mm_Drill0.5mm | test point
U1 | 1 | STM32F103C8T6 | STM32F103C8Tx | Package_QFP:LQFP-48_7x7mm_P0.5mm | STMicroelectronics Arm Cortex-M3 MCU, 64KB flash, 20KB RAM, 72 MHz, 2.0-3.6V, 37 GPIO, LQFP48
U2 | 1 | TXS0108EPW | TXS0108EPW | Package_SO:TSSOP-20_4.4x6.5mm_P0.65mm | Bidirectional level-shifting voltage translator, TSSOP-20
U3 | 1 | AMS1117-3.3 | AMS1117-3.3 | Package_TO_SOT_SMD:SOT-223-3_TabPin2 | 1A Low Dropout regulator, positive, 3.3V fixed output, SOT-223
U4 | 1 | MAX6675ISA_ | MAX6675ISA_ | MAX6675ISA_T (5):SOIC127P600X175-8N
Y1 | 1 | ATS08A-E (8MHz) | ATS08A-E | ATS08A_E (1):ATS08A-E

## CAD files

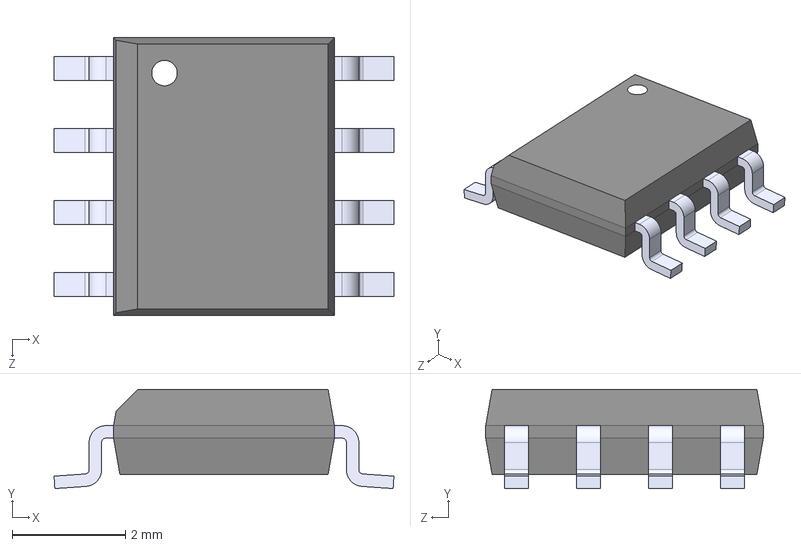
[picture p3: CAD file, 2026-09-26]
Hardware/KiCad/MAX6675ISA_T (2)/MAX6675ISA_.step
6.00 x 1.75 x 4.90 mm

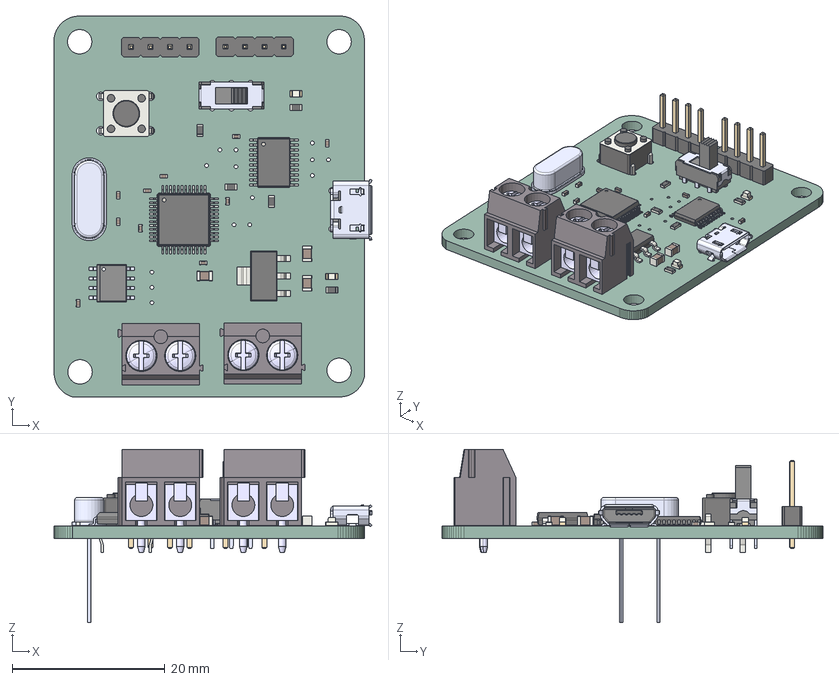
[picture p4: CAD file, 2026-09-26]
Hardware/KiCad/Reflow Project Kicad.step
41.6 x 49.8 x 22.7 mm
PinHeader_1x04_P254mm_Vertical x 2
TSSOP_20_44x65mm_P065mm
R_0603_1608Metric x 5
LED_0603_1608Metric x 2
C_0805_2012Metric x 3
C_0402_1005Metric x 10
SOT_223
S8-2_21-0041
SW_PUSH_6mm
ATS08A-E
LQFP_48_7x7mm_P05mm
EG1271A
Reflow Project Kicad PCB

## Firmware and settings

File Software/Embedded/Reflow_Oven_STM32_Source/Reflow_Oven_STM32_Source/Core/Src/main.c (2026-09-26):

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
/* Includes ------------------------------------------------------------------*/
#include "main.h"

/* USER CODE BEGIN Includes */
#define ARM_MATH_CM3
#include "arm_math.h"
#include "FLASH_PAGE.h"
#include "stdio.h"
#include <stdlib.h>
#include "string.h"
/* USER CODE END Includes */

SPI_HandleTypeDef hspi1;

TIM_HandleTypeDef htim1;
TIM_HandleTypeDef htim4;

UART_HandleTypeDef huart1;

PCD_HandleTypeDef hpcd_USB_FS;

void SystemClock_Config(void);
static void MX_GPIO_Init(void);
static void MX_SPI1_Init(void);
static void MX_TIM4_Init(void);
static void MX_TIM1_Init(void);
static void MX_USART1_UART_Init(void);
static void MX_USB_PCD_Init(void);
/* USER CODE BEGIN 0 */

typedef struct {
	float32_t KP ;
	float32_t Ki ;
	float32_t KD ;
	float32_t firstHeatUpRate;
	uint32_t SoakTempeture ;
	uint32_t SoakTime ;
	float32_t secondHeatUpRate;
	uint32_t ReflowTempeture ;
	uint32_t ReflowTime;
}ReflowTemplate;

uint8_t data[2];
uint8_t ReflowCurve[4000];
float temp;
float duty;
uint32_t data_flash[] = {400, 200, 0, 50, 900, 2};
arm_pid_instance_f32 PID;
ReflowTemplate ReflowParameters;
uint8_t ReflowEnable = 0;
uint16_t ReflowIndex = 0;
float32_t debug = 0;
uint8_t Cmd_End[3] = {0xFF, 0xFF, 0xFF};
uint8_t UART_Recieved_Data[5]={'p','0','x','x','x'};
uint8_t UART_Recieved_Flag = 0;
char input[20];
uint16_t PhaseIndex[5]={0};
char ConsoleMSG[20];


//ReflowTemplate ReflowDebug;

//char test2[5]={'1','.','2','3','4'};
uint8_t test2[5] = {'p','0','x','x','x'};

//void FlashReflowParameters(){
////Flash_Write_Data(0x0801FC00, (uint32_t*)ReflowParameters, 9);
//
//int i;
//uint8_t *data_p = &ReflowParameters;
//uint64_t flash_address = 0x0801FC00;//put first flash address here
//HAL_FLASH_Unlock();
//for ( i = 0; i < sizeof(ReflowTemplate); i++, data_p++, flash_address++ )
//    HAL_FLASH_Program(FLASH_TYPEPROGRAM_WORD, flash_address, *data_p);
//HAL_FLASH_Lock();
//}

void SaveParameters(){
	Flash_Write_Data(0x0801FC00, &ReflowParameters, 9);
}






void HAL_UART_RxCpltCallback(UART_HandleTypeDef *huart){
	HAL_UART_Receive_IT(&huart1, UART_Recieved_Data, 5);
	UART_Recieved_Flag =1;
}

void NEXTION_SendString (char *ID, char *string){
	char buf[50];
	int len = sprintf(buf, "%s.txt=\"%s\"", ID, string);
	HAL_UART_Transmit(&huart1, (uint8_t *)buf, len, 1000);
	HAL_UART_Transmit(&huart1, Cmd_End, 3, 100);

}

void NEXTION_SendFloat (char *ID, float32_t number){
	char buf[50];
	int len = sprintf(buf, "%s.txt=\"%.2f\"", ID, number);
	HAL_UART_Transmit(&huart1, (uint8_t *)buf, len, 1000);
	HAL_UART_Transmit(&huart1, Cmd_End, 3, 100);
}

void NEXTION_SenduInt (char *ID, uint32_t number){
	char buf[50];
	int len = sprintf(buf, "%s.txt=\"%lu\"", ID, number);
	HAL_UART_Transmit(&huart1, (uint8_t *)buf, len, 1000);
	HAL_UART_Transmit(&huart1, Cmd_End, 3, 100);
}

void NEXTION_CMD (char *string){
	HAL_UART_Transmit(&huart1, (uint8_t *)string, strlen(string), 1000);
	HAL_UART_Transmit(&huart1, Cmd_End, 3, 100);
}

void UpdatePage(){
	NEXTION_SendFloat("t1",ReflowParameters.firstHeatUpRate);
	NEXTION_SenduInt("t2", ReflowParameters.SoakTempeture);
	NEXTION_SenduInt("t3", ReflowParameters.SoakTime);
	NEXTION_SendFloat("t4",ReflowParameters.secondHeatUpRate);
	NEXTION_SenduInt("t5", ReflowParameters.ReflowTempeture);
	NEXTION_SenduInt("t6", ReflowParameters.ReflowTime);
}

void NextionDrawDot(uint32_t x, uint32_t y){

	char buf[50];
	int len = sprintf(buf, "cirs %lu,%lu,2,BLUE", x, y);
	HAL_UART_Transmit(&huart1, (uint8_t *)buf, len, 1000);
	HAL_UART_Transmit(&huart1, Cmd_End, 3, 100);
}

void NextionDrawTemp(uint32_t x, uint32_t y){

	char buf[50];
	int len = sprintf(buf, "cirs %lu,%lu,2,RED", x, y);
	HAL_UART_Transmit(&huart1, (uint8_t *)buf, len, 1000);
	HAL_UART_Transmit(&huart1, Cmd_End, 3, 100);
}



float32_t HandleKeyPad() {

	//clear Input
	for (int i = 0; i < 20; i++) {
		input[i] = 0;
	}

	uint8_t index = 0;

	NEXTION_SendString("t0", "");
	UART_Recieved_Flag = 0;

	while (strncmp((char*) UART_Recieved_Data, "enter", 5) != 0) {

		if(strncmp((char*) UART_Recieved_Data, "abbre", 5) == 0)
				return 9999;
		if(strncmp((char*) UART_Recieved_Data, "kback", 5) == 0)
				return 8888;


		if (UART_Recieved_Flag == 1) {
			input[index] = UART_Recieved_Data[4];
			UART_Recieved_Flag = 0;
			index++;
			NEXTION_SendString("t0", input);
		}
	}
	return atof(input);
}


void Update_Page_3() {
	uint8_t defaultUart[5] = {'p','3','x','x','x'};
	for(int i=0;i<5;i++){
		UART_Recieved_Data[i]=defaultUart[i];
	}

	NEXTION_SendFloat("t0", ReflowParameters.firstHeatUpRate);
	NEXTION_SenduInt("t1", ReflowParameters.SoakTime);
	NEXTION_SenduInt("t2", ReflowParameters.SoakTempeture);
	NEXTION_SendFloat("t3", ReflowParameters.secondHeatUpRate);
	NEXTION_SenduInt("t4", ReflowParameters.ReflowTime);
	NEXTION_SenduInt("t5", ReflowParameters.ReflowTempeture);

}

void Update_Page_0() {
	uint8_t defaultUart[5] = {'p','0','x','x','x'};
	for(int i=0;i<5;i++){
		UART_Recieved_Data[i]=defaultUart[i];
	}

	float32_t dx = 0.625/4; //275px / 400s
	float32_t dy = 0.8333; //200px / 240 Grad
	uint32_t OffsetX = 35;
	uint32_t OffsetY = 230;

		//Reflow Aktuelle Temperatur anzeigen:
		if (ReflowEnable == 1)
			NextionDrawTemp(OffsetX + (uint32_t)((float32_t)(ReflowIndex)*dx), OffsetY - (uint32_t)((float32_t)(temp)*dy));



	NEXTION_SendFloat("t0", temp);
	NEXTION_SendFloat("t1", ReflowParameters.firstHeatUpRate);
	NEXTION_SenduInt("t3", ReflowParameters.SoakTime);
	NEXTION_SenduInt("t2", ReflowParameters.SoakTempeture);
	NEXTION_SendFloat("t4", ReflowParameters.secondHeatUpRate);
	NEXTION_SenduInt("t6", ReflowParameters.ReflowTime);
	NEXTION_SenduInt("t5", ReflowParameters.ReflowTempeture);
	NEXTION_SendString("g1", ConsoleMSG);

}

void Update_Page_2() {
	uint8_t defaultUart[5] = {'p','2','x','x','x'};
	for(int i=0;i<5;i++){
		UART_Recieved_Data[i]=defaultUart[i];
	}

	NEXTION_SendFloat("t0", ReflowParameters.KP);
	NEXTION_SendFloat("t1", ReflowParameters.Ki);
	NEXTION_SendFloat("t2", ReflowParameters.KD);
}



void HandleGui(){
	//###################Page0##########################

	if(strncmp((char *)UART_Recieved_Data, "p0xxx", 5) == 0){
			Update_Page_0();
			}

	if(strncmp((char *)UART_Recieved_Data, "p0b02", 5) == 0){
			Update_Page_3();
			}

	if(strncmp((char *)UART_Recieved_Data, "p0b00", 5) == 0){
			startReflow();
			Update_Page_0();
			}

	if(strncmp((char *)UART_Recieved_Data, "p0b01", 5) == 0){
			stopReflow();
			Update_Page_0();
			}

	if(strncmp((char *)UART_Recieved_Data, "p0b02", 5) == 0){
			Update_Page_3();
			}


	//###################Page2##########################

	  if(strncmp((char *)UART_Recieved_Data, "p2xxx", 5) == 0){
		Update_Page_2();
		}

		  if(strncmp((char *)UART_Recieved_Data, "p2b00", 5) == 0){
			  float32_t Output =0;
			  Output = HandleKeyPad();
			  while(Output == 9999){
					uint8_t defaultUart[5] = {'x','x','x','x','x'};
					for(int i=0;i<5;i++){
						UART_Recieved_Data[i]=defaultUart[i];
					}
				  Output = HandleKeyPad();
			  }
			  if(Output == 8888){
				 Output = ReflowParameters.KP;
			  }
	    ReflowParameters.KP = Output;
	    PID.Kp = ReflowParameters.KP;
		arm_pid_init_f32(&PID, 1);
		Update_Page_2();
		NEXTION_CMD("page 2");

		}

		  if(strncmp((char *)UART_Recieved_Data, "p2b01", 5) == 0){
			  float32_t Output =0;
			  Output = HandleKeyPad();
			  while(Output == 9999){
					uint8_t defaultUart[5] = {'x','x','x','x','x'};
					for(int i=0;i<5;i++){
						UART_Recieved_Data[i]=defaultUart[i];
					}
				  Output = HandleKeyPad();
			  }
			  if(Output == 8888){
				 Output = ReflowParameters.Ki;
			  }
			  ReflowParameters.Ki = Output;
			  	    PID.Ki = ReflowParameters.Ki;
			arm_pid_init_f32(&PID, 1);
			Update_Page_2();
			NEXTION_CMD("page 2");

		}

		  if(strncmp((char *)UART_Recieved_Data, "p2b02", 5) == 0){
			  float32_t Output =0;
			  Output = HandleKeyPad();
			  while(Output == 9999){
					uint8_t defaultUart[5] = {'x','x','x','x','x'};
					for(int i=0;i<5;i++){
						UART_Recieved_Data[i]=defaultUart[i];
					}
				  Output = HandleKeyPad();
			  }
			  if(Output == 8888){
				 Output = ReflowParameters.KD;
			  }
			  ReflowParameters.KD = Output;
			 			  	    PID.Kd = ReflowParameters.KD;
			arm_pid_init_f32(&PID, 1);
			Update_Page_2();
			NEXTION_CMD("page 2");

		}

		  if(strncmp((char *)UART_Recieved_Data, "p2b03", 5) == 0){
			Update_Page_3();
		}







	//###################Page 3########################

	  if(strncmp((char *)UART_Recieved_Data, "p3xxx", 5) == 0){
		Update_Page_3();
		}

		  if(strncmp((char *)UART_Recieved_Data, "p3b00", 5) == 0){
			  float32_t Output =0;
			  Output = HandleKeyPad();
			  while(Output == 9999){
					uint8_t defaultUart[5] = {'x','x','x','x','x'};
					for(int i=0;i<5;i++){
						UART_Recieved_Data[i]=defaultUart[i];
					}
				  Output = HandleKeyPad();
			  }
			  if(Output == 8888){
				 Output = ReflowParameters.firstHeatUpRate;
			  }

			  if(Output < 0.2)
				  Output = 0.2;

		ReflowParameters.firstHeatUpRate = Output;
		Update_Page_3();
		NEXTION_CMD("page 3");
		calculateReflowCurve();

		}
		//NEXTION_SendFloat("t0", ReflowParameters.firstHeatUpRate);

		  if(strncmp((char *)UART_Recieved_Data, "p3b01", 5) == 0){
			  float32_t Output =0;
			  Output = HandleKeyPad();
			  while(Output == 9999){
					uint8_t defaultUart[5] = {'x','x','x','x','x'};
					for(int i=0;i<5;i++){
						UART_Recieved_Data[i]=defaultUart[i];
					}
				  Output = HandleKeyPad();
			  }
			  if(Output == 8888){
				 Output = ReflowParameters.SoakTime;
			  }
			ReflowParameters.SoakTime = Output;
			Update_Page_3();
			NEXTION_CMD("page 3");
			calculateReflowCurve();

		}
		//NEXTION_SendFloat("t0", ReflowParameters.firstHeatUpRate);

		  if(strncmp((char *)UART_Recieved_Data, "p3b02", 5) == 0){
			  float32_t Output =0;
			  Output = HandleKeyPad();
			  while(Output == 9999){
					uint8_t defaultUart[5] = {'x','x','x','x','x'};
					for(int i=0;i<5;i++){
						UART_Recieved_Data[i]=defaultUart[i];
					}
				  Output = HandleKeyPad();
			  }
			  if(Output == 8888){
				 Output = ReflowParameters.SoakTempeture;
			  }
			ReflowParameters.SoakTempeture = Output;
			Update_Page_3();
			NEXTION_CMD("page 3");
			calculateReflowCurve();

		}
		//NEXTION_SendFloat("t0", ReflowParameters.firstHeatUpRate);

		  if(strncmp((char *)UART_Recieved_Data, "p3b03", 5) == 0){
			  float32_t Output =0;
			  Output = HandleKeyPad();
			  while(Output == 9999){
					uint8_t defaultUart[5] = {'x','x','x','x','x'};
					for(int i=0;i<5;i++){
						UART_Recieved_Data[i]=defaultUart[i];
					}
				  Output = HandleKeyPad();
			  }
			  if(Output == 8888){
				 Output = ReflowParameters.secondHeatUpRate;
			  }
			  if(Output < 0.2)
						  Output = 0.2;
			ReflowParameters.secondHeatUpRate = Output;
			Update_Page_3();
			NEXTION_CMD("page 3");
			calculateReflowCurve();

		}


		//NEXTION_SendFloat("t0", ReflowParameters.firstHeatUpRate);

		  if(strncmp((char *)UART_Recieved_Data, "p3b04", 5) == 0){
			  float32_t Output =0;
			  Output = HandleKeyPad();
			  while(Output == 9999){
					uint8_t defaultUart[5] = {'x','x','x','x','x'};
					for(int i=0;i<5;i++){
						UART_Recieved_Data[i]=defaultUart[i];
					}
				  Output = HandleKeyPad();
			  }
			  if(Output == 8888){
				 Output = ReflowParameters.ReflowTime;
			  }
			ReflowParameters.ReflowTime = Output;
			Update_Page_3();
			NEXTION_CMD("page 3");
			calculateReflowCurve();

		}
		//NEXTION_SendFloat("t0", ReflowParameters.firstHeatUpRate);

		  if(strncmp((char *)UART_Recieved_Data, "p3b05", 5) == 0){
			  float32_t Output =0;
			  Output = HandleKeyPad();
			  while(Output == 9999){
					uint8_t defaultUart[5] = {'x','x','x','x','x'};
					for(int i=0;i<5;i++){
						UART_Recieved_Data[i]=defaultUart[i];
					}
				  Output = HandleKeyPad();
			  }
			  if(Output == 8888){
				 Output = ReflowParameters.ReflowTempeture;
			  }
			ReflowParameters.ReflowTempeture = Output;
			Update_Page_3();
			NEXTION_CMD("page 3");
			calculateReflowCurve();

		}

		  if(strncmp((char *)UART_Recieved_Data, "p3b06", 5) == 0){
			Update_Page_2();
		}

		  if(strncmp((char *)UART_Recieved_Data, "p3b07", 5) == 0){
			Update_Page_0();
			Draw_Reflow_Curve();
			SaveParameters();
		}
		//NEXTION_SendFloat("t0", ReflowParameters.firstHeatUpRate);


//	NEXTION_SendFloat("t0",ReflowParameters.firstHeatUpRate );
//	NEXTION_SenduInt("t1",ReflowParameters.SoakTime );
//	NEXTION_SenduInt("t2",ReflowParameters.SoakTempeture );
//	NEXTION_SendFloat("t3",ReflowParameters.secondHeatUpRate );
//	NEXTION_SenduInt("t4",ReflowParameters.ReflowTime );
//	NEXTION_SenduInt("t5",ReflowParameters.ReflowTempeture );
}




void HAL_TIM_PeriodElapsedCallback(TIM_HandleTypeDef *htim) {
	float32_t dx = 0.625/4; //275px / 880s / 500ms
	float32_t dy = 0.8333; //200px / 240 Grad
	uint32_t OffsetX = 35;
	uint32_t OffsetY = 230;

	if (htim == &htim4) {
		//Read Thermocouple every 500ms:
		HAL_GPIO_WritePin(CS_GPIO_Port, CS_Pin, 0);
		HAL_SPI_Receive(&hspi1, data, 2, 100);
		HAL_GPIO_WritePin(CS_GPIO_Port, CS_Pin, 1);
		temp = ((((uint16_t) data[1] << 8) | data[2]) >> 3) * 0.249;

		//Reflow Prozess Einleiten:
		if (ReflowEnable == 1) {
			//NextionDrawTemp(OffsetX + (uint32_t)((float32_t)(ReflowIndex)*dx), OffsetY - (uint32_t)((float32_t)(temp)*dy));

			if(ReflowIndex == PhaseIndex[0])
				sprintf(ConsoleMSG,"HEAT UP");
			if(ReflowIndex == PhaseIndex[1])
				sprintf(ConsoleMSG,"SOAK");
			if(ReflowIndex == PhaseIndex[2])
				sprintf(ConsoleMSG,"HEAT UP");
			if(ReflowIndex == PhaseIndex[3])
				sprintf(ConsoleMSG,"REFLOW");
			if(ReflowIndex == PhaseIndex[4])
				sprintf(ConsoleMSG,"COOL DOWN");


			//Regelabweichung
			float pid_error =  ReflowCurve[ReflowIndex] - temp;
			//Stellgroesse
			duty =  arm_pid_f32(&PID, pid_error);

			//Stellgrößenbegrenzung
			if (duty > 1000) {
				duty = 1000;
			} else if (duty < 0) {
				duty = 0;
			}

			//Dutycycle Anpassen
			htim1.Instance->CCR1 = (uint16_t)duty;

			ReflowIndex++;
			//Abbruchbedingung
			if (ReflowIndex == PhaseIndex[4]) {
				sprintf(ConsoleMSG,"FINISHED");
				ReflowEnable = 0;
			}

		} else {
			ReflowIndex = 0;
			//Dutycycle = 0
			htim1.Instance->CCR1 = 0;
		}

	}

}

void setReflowParameters(){
	ReflowParameters.KP = 10;
	ReflowParameters.Ki = 10;
	ReflowParameters.KD = 0;
	ReflowParameters.firstHeatUpRate = 1.2;
	ReflowParameters.SoakTempeture = 100;
	ReflowParameters.SoakTime = 100;
	ReflowParameters.secondHeatUpRate = 1.2;
	ReflowParameters.ReflowTempeture = 210;
	ReflowParameters.ReflowTime =100;
	sprintf(ConsoleMSG,"IDLE");
}

void calculateReflowCurve(){
	for(int i =0;i<4000;i++){
		ReflowCurve[i]=0;
	}

	int index = 0;
	float timestep = 0.5;
	//First Heat Up:
	while (24 + timestep * ReflowParameters.firstHeatUpRate <= ReflowParameters.SoakTempeture) {
	ReflowCurve[index] = 24 + timestep * ReflowParameters.firstHeatUpRate;
	index++;
	timestep = timestep + 0.5;
	}
	PhaseIndex[1]=index;

	//Soak
	int Soakduration = 2*ReflowParameters.SoakTime;

	for(int i=0;i<Soakduration;i++){
		ReflowCurve[index+i]=ReflowParameters.SoakTempeture;
	}


	//Second Heat Up:
	index = index + Soakduration;
	PhaseIndex[2]=index;
	timestep = 0.5;
	while (ReflowParameters.SoakTempeture + timestep * ReflowParameters.secondHeatUpRate <= ReflowParameters.ReflowTempeture) {
	ReflowCurve[index] = ReflowParameters.SoakTempeture + (uint8_t)timestep * ReflowParameters.secondHeatUpRate;
	index++;
	timestep = timestep + 0.5;
	}
	PhaseIndex[3]=index;

	//Reflow
	int Reflowduration = 2*ReflowParameters.ReflowTime;

	for(int i=0;i<Reflowduration;i++){
		ReflowCurve[index+i]=ReflowParameters.ReflowTempeture;
	}

	index = index + Reflowduration;
	ReflowCurve[index]=0;
	PhaseIndex[4]=index;

	//Cooldown
	timestep = 0.5;
	while (ReflowParameters.ReflowTempeture - timestep * 1.8 >= 24) {
	ReflowCurve[index] = ReflowParameters.ReflowTempeture - timestep * 1.8;
	index++;
	timestep = timestep + 0.5;
	}




}

void Draw_Reflow_Curve(){
	float32_t dx = 0.625 / 4; //275px / 880s / 500 ms
	float32_t dy = 0.8333; //200px / 240 Grad
	uint32_t OffsetX = 35;
	uint32_t OffsetY = 230;
	uint32_t index = 0;



	while(ReflowCurve[index] != 0){

		NextionDrawDot(OffsetX + (uint32_t)((float32_t)(index)*dx), OffsetY - (uint32_t)((float32_t)(ReflowCurve[index])*dy));
		index= index + 4;

		if(strncmp((char *)UART_Recieved_Data, "p0b02", 5) == 0)
			break;
	}
}



void startReflow(){
ReflowEnable = 1;
NEXTION_CMD("page 0");
Draw_Reflow_Curve();
Update_Page_0();

}

void stopReflow(){
	if(ReflowEnable ==1){
	ReflowEnable = 0;
	sprintf(ConsoleMSG,"STOPPED");
	Update_Page_0();
	}
}

/* USER CODE END 0 */

/**
  * @brief  The application entry point.
  * @retval int
  */
int main(void)
{
  /* USER CODE BEGIN 1 */

	setReflowParameters();
	Flash_Read_Data(0x0801FC00, &ReflowParameters);
	calculateReflowCurve();




	PID.Kp = ReflowParameters.KP;
	PID.Ki = ReflowParameters.Ki;
	PID.Kd = ReflowParameters.KD;

	arm_pid_init_f32(&PID, 1);

  /* USER CODE END 1 */

  /* MCU Configuration--------------------------------------------------------*/

  /* Reset of all peripherals, Initializes the Flash interface and the Systick. */
  HAL_Init();

  /* Configure the system clock */
  SystemClock_Config();

  /* Initialize all configured peripherals */
  MX_GPIO_Init();
  MX_SPI1_Init();
  MX_TIM4_Init();
  MX_TIM1_Init();
  MX_USART1_UART_Init();
  MX_USB_PCD_Init();
  /* USER CODE BEGIN 2 */
  HAL_TIM_Base_Start_IT(&htim4);
  HAL_TIM_PWM_Start(&htim1, TIM_CHANNEL_1);

  htim1.Instance->CCR1 = 10;

  //startReflow();
	HAL_Delay(2000);
  HAL_UART_Receive_IT(&huart1, UART_Recieved_Data, 5);
 sprintf(ConsoleMSG,"IDLE");
 Update_Page_0();
  Draw_Reflow_Curve();
  HAL_UART_Receive_IT(&huart1, UART_Recieved_Data, 5);
 // SaveParameters();



  //HAL_Delay(1000);

  /* USER CODE END 2 */

  /* Infinite loop */
  /* USER CODE BEGIN WHILE */
  while (1)
  {
    /* USER CODE END WHILE */

    /* USER CODE BEGIN 3 */
	  //char k[] = "1.2";
	  //debug = atof(k);

	  //debug = ReflowCurve[ReflowIndex];
//	  if(UART_Recieved_Data[3] == '1'){
//	  NEXTION_SendFloat("t0",33);
//	  debug = 5;
//	  }
//	  else{
//      NEXTION_SendFloat("t0",66);
//      debug = 3;
//	  }
	  HandleGui();
	  HAL_Delay(500);


	  if(strncmp((char *)UART_Recieved_Data, "p0xxx", 5) == 0){


		  debug = 5;

	  }

	  //NextionDrawDot(200,200);



	  //debug = HandleKeyPad();
	  //debug = atof(input);

	  //UpdatePage();



  }
  /* USER CODE END 3 */
}

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


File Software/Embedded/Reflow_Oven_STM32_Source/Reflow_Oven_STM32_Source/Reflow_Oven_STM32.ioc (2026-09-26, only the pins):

Mcu.UserName=STM32F103C8Tx
PA11.Signal=USB_DM
PA12.Signal=USB_DP
PA13.Signal=SYS_JTMS-SWDIO
PA14.Signal=SYS_JTCK-SWCLK
PA4.GPIO_Label=CS
PA4.Signal=GPIO_Output
PA5.Signal=SPI1_SCK
PA6.Signal=SPI1_MISO
PA8.Signal=S_TIM1_CH1
PB6.Signal=USART1_TX
PB7.Signal=USART1_RX
PD0-OSC_IN.Signal=RCC_OSC_IN
PD1-OSC_OUT.Signal=RCC_OSC_OUT

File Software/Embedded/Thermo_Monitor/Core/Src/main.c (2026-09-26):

/**
 * Reflow Oven - MAX6675 thermocouple live monitor
 *
 * Board: STM32F103C8T6 (Reflow Project Kicad rev.)
 *   MAX6675 (U4)  ~CS  -> PA4   (GPIO, software chip select)
 *                  SCK -> PA5   (GPIO, bit-banged clock)
 *                  SO  -> PA6   (GPIO input, pulled up)
 *   USART1 TX     -> PA9  (test point TP6)
 *   USART1 RX     -> PA10 (test point TP5)
 *   Relay         -> PA8  (J6, TIM1_CH1) - heater PWM in the CONTROL_MODE
 *                   builds, held low otherwise. See control.c.
 *
 * Temperature is reported three ways so it can be observed with or without
 * extra hardware:
 *   1. USART1 @ 115200 8N1 on PA9/TP6, plain ASCII lines.
 *   2. ARM semihosting over SWD, so an attached ST-Link prints the same lines
 *      without needing a USB-serial adapter.
 *   3. A telemetry struct at a fixed RAM address that a debugger can poll
 *      while the core keeps running.
 */

#include "main.h"
#include "thermo.h"
#include <stdio.h>
#include <string.h>

/* ---- MAX6675 ------------------------------------------------------------ */
/* The startup probe exists only to tell a wiring fault from a protocol fault,
 * and it costs a second or two. Left off now that the sensor reads correctly;
 * set to 1 if the MAX6675 ever goes quiet again. */
#define RUN_BUS_PROBE      0

/* Built with `make SCK_TEST=1`: instead of monitoring, hold CS low and drive
 * SCK as a 1 kHz square wave forever, so the clock line can be chased with a
 * meter. A 50% square wave reads about half of 3.3V on a DC multimeter, so
 * TP3 and U4 pin 5 should both sit near 1.6V. TP3 at 1.6V with pin 5 stuck at
 * 0V or 3.3V means the joint or trace at the chip is open. */
#ifndef SCK_TEST_MODE
#define SCK_TEST_MODE      0
#endif

/* One conversion takes up to 220 ms, so never sample faster than that. */
#define SAMPLE_PERIOD_MS   500u

#define CS_GPIO_Port       GPIOA
#define CS_Pin             GPIO_PIN_4
#define SCK_GPIO_Port      GPIOA
#define SCK_Pin            GPIO_PIN_5
#define SO_GPIO_Port       GPIOA
#define SO_Pin             GPIO_PIN_6

/* ---- Telemetry block read by the debugger while the core runs ----------- */
#define TELEM_MAGIC        0x544D5031u   /* "TMP1" */

typedef struct {
	uint32_t magic;
	uint32_t seq;        /* increments once per completed sample */
	uint32_t raw;        /* raw 16-bit MAX6675 word */
	int32_t  milli_c;    /* temperature in milli-degrees C */
	uint32_t fault;      /* FAULT_* */
	uint32_t uptime_ms;
	uint32_t sysclk_hz;  /* which clock actually came up, as a frequency */
	uint32_t on_hse;     /* 1 = crystal, 0 = internal oscillator */
} telem_t;

volatile telem_t g_telem __attribute__((used)) = { TELEM_MAGIC, 0, 0, 0, 0, 0, 0, 0 };

UART_HandleTypeDef huart1;

static void SystemClock_Config(void);
static void MX_GPIO_Init(void);
static void MX_USART1_UART_Init(void);
void Error_Handler(void);

/* ---- Semihosting -------------------------------------------------------- */
/* SYS_WRITE0 (0x04) writes a NUL-terminated string to the debugger console.
 * Guarded on C_DEBUGEN: with no debugger attached the BKPT would fault, so
 * the board still runs standalone. */
static int debugger_attached(void)
{
	return (CoreDebug->DHCSR & CoreDebug_DHCSR_C_DEBUGEN_Msk) != 0;
}

static void semihost_write0(const char *s)
{
	if (!debugger_attached()) {
		return;
	}
	register int r0 __asm__("r0") = 0x04;
	register const char *r1 __asm__("r1") = s;
	__asm__ volatile("bkpt #0xAB" : "+r"(r0) : "r"(r1) : "memory");
}

/* Semihosting only - for when USART1 belongs to something else. */
void emit_dbg(const char *s)
{
	semihost_write0(s);
}

/* Send one line out every available channel. */
void emit(const char *s)
{
	HAL_UART_Transmit(&huart1, (uint8_t *)s, strlen(s), 100);
	semihost_write0(s);
}

/* ---- MAX6675 read (bit-banged) -----------------------------------------
 *
 * Frame layout (MSB first):
 *   D15      dummy sign bit, always 0
 *   D14..D3  12-bit temperature, 0.25 C per LSB
 *   D2       1 = thermocouple input open
 *   D1       device ID, always 0
 *   D0       tri-state
 *
 * Clocked by hand rather than through SPI1: the part only needs 16 clocks and
 * this removes any doubt about CPOL/CPHA or the receive-only clock gating.
 * SO is sampled while SCK is low, then SCK is pulsed to shift the next bit.
 */
static void bb_delay(void)
{
	for (volatile int i = 0; i < 40; i++) {
		__NOP();
	}
}

static void sck_write(int level)
{
	HAL_GPIO_WritePin(SCK_GPIO_Port, SCK_Pin, level ? GPIO_PIN_SET : GPIO_PIN_RESET);
}

static int so_read(void)
{
	return HAL_GPIO_ReadPin(SO_GPIO_Port, SO_Pin) == GPIO_PIN_SET;
}

uint32_t max6675_read(uint16_t *word_out)
{
	uint16_t word = 0;

	sck_write(0);
	HAL_GPIO_WritePin(CS_GPIO_Port, CS_Pin, GPIO_PIN_RESET);
	bb_delay();

	for (int bit = 15; bit >= 0; bit--) {
		sck_write(0);
		bb_delay();
		if (so_read()) {
			word |= (uint16_t)(1u << bit);
		}
		sck_write(1);
		bb_delay();
	}

	sck_write(0);
	HAL_GPIO_WritePin(CS_GPIO_Port, CS_Pin, GPIO_PIN_SET);

	*word_out = word;

	/* A real reply always has D15 = 0 and D1 = 0. All-ones means nothing is
	 * driving SO (the pull-up wins); all-zeros means SO is stuck low. Neither
	 * is a temperature, so don't report one. */
	if (word == 0x0000u || word == 0xFFFFu || (word & 0x8002u) != 0u) {
		return FAULT_FRAMING;
	}
	if ((word & 0x0004u) != 0u) {
		return FAULT_OPEN_TC;
	}
	return FAULT_NONE;
}

/* Pin-to-pin short test.
 *
 * On the SOIC-8 the MAX6675's signal pins are adjacent: 5 = SCK, 6 = ~CS,
 * 7 = SO. A solder bridge between 6 and 7 reproduces the all-zeros symptom
 * exactly - SO would simply mirror whatever CS is doing, reading high while
 * deselected and low throughout a transfer - so it has to be ruled out before
 * blaming an open SCK.
 *
 * The trick is the pull direction. Whenever CS is high the MAX6675 releases
 * SO, so a pulled-down SO must read 0. If it reads 1, something other than
 * the part is driving it, and CS is the only candidate next door.
 */
static void cfg_pin(GPIO_TypeDef *port, uint16_t pin, uint32_t mode, uint32_t pull)
{
	GPIO_InitTypeDef gpio = {0};
	gpio.Pin = pin;
	gpio.Mode = mode;
	gpio.Pull = pull;
	gpio.Speed = GPIO_SPEED_FREQ_HIGH;
	HAL_GPIO_Init(port, &gpio);
}
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

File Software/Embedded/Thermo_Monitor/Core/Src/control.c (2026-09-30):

/**
 * Heater control for the Reflow Oven board.
 *
 * The heating element is switched by an IRF520N on PA8 (the "Relay" net, J6),
 * which is TIM1_CH1, so the duty cycle is real hardware PWM rather than
 * bit-banged. D3 sits on the same net and dims with duty, which makes the
 * output visible from across the bench.
 *
 * Two builds, selected by CONTROL_MODE:
 *   1 = closed loop. PI control through a setpoint schedule.
 *   2 = open loop step. Holds a fixed duty so the plant can be characterised
 *       before anyone tries to pick gains for it.
 *   3 = hold a fixed duty, for probing the driver stage with a meter.
 *   4 = setpoint server, steered from a host over SWD. See webapp/.
 *   5 = Nextion HMI probe: find the display, then watch its touch codes.
 *
 * Safety, in order of how much it is relied on:
 *   - Any sensor fault forces duty to 0. A controller that cannot see the
 *     temperature must not be driving a heater.
 *   - Above OVERTEMP_C the output latches off for good and needs a reset.
 *   - Every stage has a timeout, so a heater too weak to reach setpoint ends
 *     the run instead of sitting at full power forever.
 *   - The profile switches off and reports DONE when it finishes.
 *   - The host script separately forces PA8 low after every run, so a halted
 *     core cannot leave the element energised. See run_profile.sh.
 */

#include "thermo.h"
#include <stdio.h>
#include <string.h>
#include <stdlib.h>

#if CONTROL_MODE

/* ---- PWM ---------------------------------------------------------------- */
/* Switching frequency, in Hz. 200 Hz suits a MOSFET driven directly from the
 * pin. An opto-isolated DC solid state relay does NOT switch that fast - turn
 * on and off take on the order of a millisecond, which is a large slice of a
 * 5 ms period, so it would never fully switch and would dissipate heat in the
 * transition. Heaters driven by an SSR use time-proportioned control instead:
 *   make MODE=pi PWM_HZ=1
 * A thermal plant with a minutes-long time constant does not care.
 *
 * The period is always 2000 counts, so duty resolution is 0.05% whatever the
 * frequency; only the prescaler changes. */
#ifndef PWM_HZ
/* Time-proportioned, 1 Hz. The load is an SSR-25DD: it needs roughly a
 * millisecond to switch, so at 200 Hz a 1 % duty is a 48 us pulse and the
 * relay simply never turns on. Resolution stays 0.05 % because PWM_PERIOD is
 * always 2000 counts. The old 200 Hz default belonged to the IRF520N. */
#define PWM_HZ             1u
#endif
#define PWM_PERIOD         2000u

/* ---- Loop and limits ---------------------------------------------------- */
#define CTRL_PERIOD_MS     250u      /* MAX6675 conversion time is 220 ms max */
#ifndef OVERTEMP_RAW
#define OVERTEMP_RAW       120.0
#endif
#define OVERTEMP_C         ((float)(OVERTEMP_RAW))  /* latch off above this */

/* Absolute ceiling on commanded duty, baked into the build. This is a hard
 * guard, not the working limit - in server mode the host sets the working cap
 * at runtime and can change it from the UI, so leaving this at 100 keeps the
 * control honest. Lower it only to make a build that physically cannot exceed
 * some duty:
 *   make MODE=pi MAX_DUTY=25
 * The over-temperature latch is the real backstop, not this. */
#ifndef MAX_DUTY_RAW
#define MAX_DUTY_RAW       100.0
#endif

/* Tunables come in as bare numbers from the Makefile and get cast here, so
 * that both `KP=8.5` and `KP=100` are valid on the command line. */
#ifndef STEP_DUTY_RAW
#define STEP_DUTY_RAW      40.0
#endif

/* Step-test segment lengths, in seconds. This plant is slow - about a degree
 * a minute at full power - so the heating window has to be minutes, not the
 * tens of seconds that would characterise a fast heater. */
#ifndef STEP_BASE_S
#define STEP_BASE_S        4
#endif
#ifndef STEP_HEAT_S
#define STEP_HEAT_S        30
#endif
#ifndef STEP_COOL_S
#define STEP_COOL_S        30
#endif
#ifndef KP_RAW
#define KP_RAW             12.0
#endif
#ifndef KI_RAW
#define KI_RAW             0.6
#endif

static const float DUTY_MAX_PCT = (float)(MAX_DUTY_RAW);
__attribute__((unused)) static const float STEP_DUTY_PCT  = (float)(STEP_DUTY_RAW);
__attribute__((unused)) static const float KP_PCT_PER_C   = (float)(KP_RAW);
__attribute__((unused)) static const float KI_PCT_PER_C_S = (float)(KI_RAW);

#ifndef DWELL_S
#define DWELL_S            10
#endif
#define DWELL_MS           ((uint32_t)DWELL_S * 1000u)  /* hold each setpoint */
#define DWELL_TOL_C        1.0f      /* within this of setpoint counts as there */
#define STAGE_TIMEOUT_MS   150000u   /* give up on a stage after this */
#define COOLDOWN_MS        20000u    /* keep logging after the last stage */

static TIM_HandleTypeDef htim1;
static uint8_t latched_off;

/* ---- Heater ------------------------------------------------------------- */

/* Put PA8 back under the timer. heater_off() deliberately tears that down so
 * the pin is held low by the GPIO block even if the timer misbehaves, which
 * means arming again has to be explicit. */
static void heater_arm(void)
{
	GPIO_InitTypeDef gpio = {0};
	gpio.Pin = GPIO_PIN_8;
	gpio.Mode = GPIO_MODE_AF_PP;
	gpio.Speed = GPIO_SPEED_FREQ_LOW;
	HAL_GPIO_Init(GPIOA, &gpio);
	HAL_TIM_PWM_Start(&htim1, TIM_CHANNEL_1);
}

static void heater_set(float pct)
{
	if (latched_off || pct < 0.0f) {
		pct = 0.0f;
	}
	if (pct > DUTY_MAX_PCT) {
		pct = DUTY_MAX_PCT;
	}
	uint32_t cmp = (uint32_t)((pct / 100.0f) * (float)PWM_PERIOD);
	__HAL_TIM_SET_COMPARE(&htim1, TIM_CHANNEL_1, cmp);
	/* Writing CCR1 does nothing while the timer is stopped and PA8 is a plain
	 * GPIO. Commanding real output has to restore both. */
	if (cmp != 0u && (TIM1->CR1 & TIM_CR1_CEN) == 0u) {
		heater_arm();
	}
}

/* Belt and braces: stop the timer driving the pin and hold PA8 low as a plain
 * output, so the element is off even if the timer is left in a strange state. */
static void heater_off(void)
{
	heater_set(0.0f);
	HAL_TIM_PWM_Stop(&htim1, TIM_CHANNEL_1);

	GPIO_InitTypeDef gpio = {0};
	HAL_GPIO_WritePin(GPIOA, GPIO_PIN_8, GPIO_PIN_RESET);
	gpio.Pin = GPIO_PIN_8;
	gpio.Mode = GPIO_MODE_OUTPUT_PP;
	gpio.Pull = GPIO_NOPULL;
	gpio.Speed = GPIO_SPEED_FREQ_LOW;
	HAL_GPIO_Init(GPIOA, &gpio);
}
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

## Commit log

2026-09-26 Reflow oven controller: hardware, firmware, web app and project notes
    STM32F103 + MAX6675 + SSR reflow oven controller. The PI loop runs on the
    MCU and owns the duty cycle; hosts supply only a setpoint and gains.
    - Hardware/KiCad: schematic, PCB, gerbers, BOM, 3D model
    - Software/webapp: browser UI and Python/OpenOCD bridge over SWD
    - Software/Embedded/Thermo_Monitor: live firmware, seven build modes
    - Software/Embedded/Reflow_Oven_STM32_*: original 2021 firmware for reference
    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
    [BOM Reflow Project Kicad.csv, MAX6675ISA_.step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]
2026-09-27 Nextion link working: wire direct to PA9/PA10, add MODE=nextion
    The panel talks at 9600 once wired straight to the MCU pins. J4 is a dead
    end - its BSS138 shifters have the pins rotated one position, so a signal
    there lands on a MOSFET gate with no DC path onward. No level shifting is
    needed in either direction: PA10 is 5 V tolerant, and 3.3 V clears the
    panel's input threshold.
    - MODE=nextion: pushes live temperature to the panel, tracks which page is
    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
2026-09-27 MODE=nextion: panel-driven controller, not a read-only probe
    START/STOP arm the PI loop, APPLY sets setpoint and gains, and xPV/xSP/
    xDuty/xErr are pushed to the panel each cycle at x100.
    Accepts either spelling of start/stop - "p0b20"/"p0b21" or the text form
    "CMD=START"/"CMD=STOP" - so whichever the HMI ends up sending works with no
    firmware change. Neither is emitted yet; that is the remaining HMI gap.
    Safety envelope matches the web app: sensor fault forces duty to 0,
    over-temperature latches off until reset, duty is capped by NX_MAX_DUTY
    (compiled in, default 2 %, not raisable from the display), and the heater
    disarms if the panel goes quiet for 6 s.
    Also: the numeric page index of `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
    [control.c]
2026-09-27 MODE=nextion: implement the panel contract in Display/README.txt
    Start/Stop were always there - they use `prints "p0b20"`/`"p0b21"`, which an
    earlier grep for `print` missed. The firmware already parsed them; what was
    missing was the rest of the contract.
    Adds tState, tLed.bco, tMode, tAlarm + vis, tPI and the trend waveform, and
    drops the page gating on xPV/xSP/xDuty/xErr now that those are vscope=global.
    Page-local objects are still gated, tracked from the nav codes, with monitor
    correctly at page 0 rather than the 1 that was guessed before.
    Text and colours are only sent when they change. At 9600 baud the four
    numeric writes per cycle already use a quarter of the link, and spamming the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
    [control.c]
2026-09-27 MODE=nextion: receive on an interrupt, not by polling
    A 25 s bench run tripped the dead-man once with the panel plainly connected.
    The cause is timing, not wiring: the MAX6675 conversion is 220 ms of a 250 ms
    cycle and the four telemetry writes block on top of that, so the polling loop
    reached the UART with no slack left and dropped bytes. USART1_IRQn is unused
    by this project's MSP, so mode 8 claims it and receives into a ring buffer.
    A cycle that overruns now resyncs its deadline instead of chasing it, and the
    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
2026-09-27 MODE=nextion: bkcmd=0, so touch codes actually get parsed
    The panel's buttons were fine all along - `prints "p0b20",0` then
    `printh 0D 0A`, exactly the framing the parser expects. The bug was bkcmd=1,
    which makes the panel return a bare 0x01 after every command. Those acks are
    unterminated single bytes, and four telemetry writes per 250 ms cycle filled
    the 64-byte frame buffer in about four seconds. From then on every arriving
    byte was discarded, including the touch codes and the CR LF that would have
    completed them.
    It hid well. Telemetry is TX-only so the screen kept updating correctly, and
    the dead-man stayed satisfied because nx_last_rx is stamped in the ISR whether
    or not the parser is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
    [control.c]
2026-09-27 Fix two faults that left the SSR dead while the loop looked fine
    The buttons and the PI maths were right; the output path was not.
    1. heater_off() tears PA8 off the timer and drives it low through the GPIO
    block - deliberate, so the pin stays down even if the timer misbehaves.
    But heater_set() only wrote CCR1, which does nothing in that state, and
    nothing ever re-armed. MODE=nextion calls heater_off() during setup, so it
    could never produce any output at all. heater_set() now re-arms when asked
    for a non-zero duty with TIM1_CEN clear.
    2. PWM_HZ still defaulted to 200, left over from the IRF520N. At 1 % duty that
    is a 48 us pulse and an opto-isolated DC SSR needs about a m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
    [control.c]
2026-09-28 Fix anti-windup that could pin duty at the ceiling permanently
    Reported symptom: duty stuck at 2 % - the compiled ceiling - with the setpoint
    and both gains having no effect from the panel.
    The conditional-integration test was
    if (u > 0.0f && u < duty_max) { integ_err = cand; }
    which freezes the integral in BOTH directions once the output is saturated.
    Integration that would relieve the rail is exactly what must not be blocked.
    With a small Kp and any non-zero Ki the integral winds until ki * integ_err
    alone reaches duty_max, and from then on the I term by itself meets the cap:
    error goes negative, P goes negative, and the sum still clamps to the ceiling.
    The integral can never come d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
    [control.c]
2026-09-30 Setpoint ramp, clearable over-temp latch, and safe unattended runs
    Three problems, reported as "it overshoots and then gets stuck until I power
    cycle".
    **Stuck: latched_off was cleared nowhere.** It is set in three places and, in
    the whole firmware, reset in none - so one over-temperature trip meant the
    board would not heat again until power was removed. STOP now clears it, but
    only once the oven is below OVERTEMP_REARM_C (15 C of hysteresis), which keeps
    STOP a reset button rather than a bypass.
    **Overshoot: the setpoint now ramps.** A step setpoint guarantees overshoot on
    this plant whatever the gains are - roughly 27 s of thermal coast means the
    loop commands hard on a huge error and th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
    [control.c]
2026-09-30 Panel showed IDLE while heating: re-sync page-local objects
    Two faults, same root cause - the shown_* cache did not model the panel's
    page lifecycle.
    shown_state and shown_led were assigned even when the write was skipped for
    being on the wrong page, so a state change that happened away from the monitor
    page was recorded as displayed and never sent. The panel then sat on stale
    text indefinitely.
    A page load also resets page-local objects to their design values, so
    returning to the monitor page needs everything re-sent even though nothing
    changed. nx_resync forces that, set on a nav code and on any page change seen
    in a sendme reply, and cleared only once the writes have actually gone ou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
    [control.c]

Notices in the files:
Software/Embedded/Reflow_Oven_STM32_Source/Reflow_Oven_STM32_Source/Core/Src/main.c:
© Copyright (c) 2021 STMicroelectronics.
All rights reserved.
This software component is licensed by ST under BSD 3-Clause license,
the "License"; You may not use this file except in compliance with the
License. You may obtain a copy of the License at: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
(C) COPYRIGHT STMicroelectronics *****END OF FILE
